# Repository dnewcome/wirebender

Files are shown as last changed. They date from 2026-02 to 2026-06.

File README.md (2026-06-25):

# CNC Wire Bender

A CNC wire bending machine capable of bending 14 or 16 gauge steel wire into arbitrary 3D shapes using G-code.

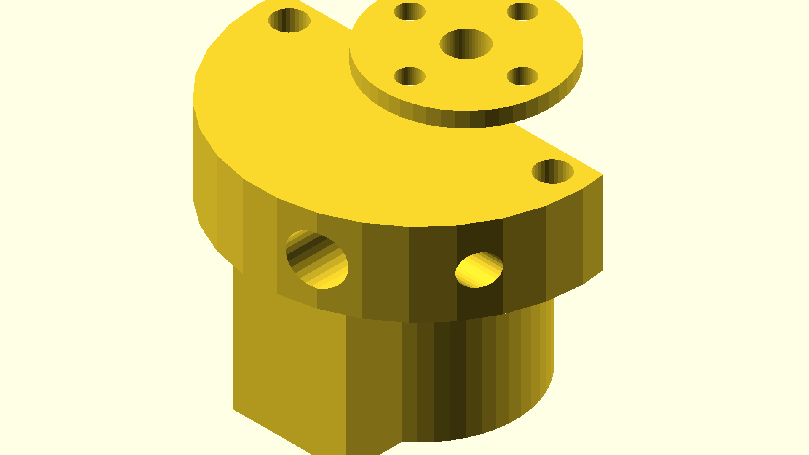
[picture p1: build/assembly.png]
Assembly


## Overview

Wire is fed from a spool using a 3D printer extruder, through a rotating feed tube. The feed tube rotation sets the bend plane (direction), and a bending head fixed to the end of the tube performs the actual bend. Motion is controlled by a GRBL 1.1 board.

## Machine Architecture

### Motion Controller
- **Controller:** GRBL 1.1
- **Input:** Standard G-code

### Wire Feed
- **Component:** Off-the-shelf 3D printer extruder
- **Wire gauge:** 14 or 16 AWG steel wire fed from a roll
- **Feed path:** Extruder → feed tube → bending head

### Feed Tube (Rotation Axis)
- Rotates around the wire axis to set the bend direction
- Driven by a geared stepper motor via toothed belt
- Supported by bearings housed in a U-shaped sheet aluminum bracket
- The U-bracket is extended to also mount the tube rotation motor

### Bending Head
- A cantilevered head clamps the end of the passive feed tube and **rotates about
  the wire axis** (Axis 2), carrying the bend mechanism around with it.
- **Bend drive (Axis 3):** a 20:1 micro-cycloidal drive + pancake
  NEMA17. A pin on the cycloidal output sweeps the wire around a fixed mandrel —
  single-pin bending; bend radius is set by the mandrel.
- **Rotation drive (Axis 2):** a pancake NEMA17 + a 12T pinion meshing a fixed 40T
  gear on the base; the rotation motor hangs at the mesh radius and doubles as a
  counterweight.
- **Tube clamp:** the head grips the feed tube on a short boss with an M3 set screw.

## Building the parts

The machine is modeled in **build123d** (`cad/*.py`), assembled into a **MuJoCo**
sim (`sim/`), and the CAD↔sim machine parameters live in one place
(`sim/machine.py`). Everything is driven by the `Makefile`:

```bash
python3 -m venv py
./py/bin/pip install build123d gggears mujoco trimesh numpy pillow networkx manifold3d

make parts        # base plate / uprights / fixed gear / spacer (printable STLs)
make head         # printable head pieces (rot + bend) + pinion + reference meshes
make cyclo-drive  # the cycloid drive: ring + disc + shaft + base + end-cap (+ fit-check)
make model        # assemble the MuJoCo model (sim/wirebender.xml) from the STLs
make view         # open the interactive sim (head auto-sweeps its limits)
make assembly     # full machine as one build123d STEP (build/assembly.step)
make              # list all targets
```

The **bend drive is fully parametric** — no external CAD file is read at build time. The
**canonical machine targets 14 ga steel on the current motor** (the 20:1 / Ø42 drive), and
the same generator scales to heavier stock by one knob:

```bash
make drive                              # what wire can this machine bend + the driver current it needs
make cyclo-drive PINS=30 MOTOR=nema23   # a complete SCALED drive (Ø60 / 30:1, NEMA23) for 1/4" stock
```

See **`docs/DRIVE_SIZING.md`** for motor/driver sizing, the scaling family, the clearance
planner, and homing. Generated artifacts land in `build/` and `sim/meshes/` (both gitignored
— reproduce from source); `STRUCTURE.md` is the repo layout, `PLAN.md` the roadmap, and
`sim/README.md` the simulation + G-code toolchain.

The cycloid internals were **validated once against a purchased reference part** (not
redistributed), then rebuilt fully parametrically — no external CAD file is needed to build
any part.

## Checklist

*The CAD, the MuJoCo simulation, and the slicer/planner/drive-sizing toolchain are well
advanced. The remaining open items are mostly physical fabrication, wiring, and on-machine
calibration.*

### Mechanical Design
- [x] Parametric bending head — rotation + bend mounts and tube clamp (`cad/rothead.py`)
- [x] Fully parametric cycloid drive — ring, disc, eccentric shaft, base, end cap; scales by
  ratio/motor (`make cyclo-drive PINS=.. MOTOR=..`)
- [x] Bend pin / mandrel geometry defined + clearance-checked in sim (`cad/bend_disc.py`, `make check-pin`)
- [x] Feeder motor mount + bracket (`cad/feeder_motor_mount.py`, `cad/feeder_bracket.py`)
- [x] Feed tube → 608-bearing sleeve adapter + bearing selection (`cad/sleeve.py`)
- [x] Rotation drive sized — 12T pinion on a fixed 40T base gear (replaces the earlier belt/pulley idea)
- [x] Homing-switch brackets, Axes 2 & 3 (`cad/home_switch.py` + `cad/arbor_mount.py` home tab)
- [ ] U-shaped sheet-aluminum feed-tube bearing bracket (fabricate)
- [ ] Wire guide / straightener between spool and feeder

### Electronics & Control
- [x] Axis assignments confirmed — Axis 1 wire feed, Axis 2 head rotation, Axis 3 bend
- [x] Stepper-driver sizing + phase-current requirements modeled per machine (`make drive`, `docs/DRIVE_SIZING.md`)
- [x] Axis limits + homing strategy defined (conventions in `sim/machine.py`, cycle in `sim/home.py`)
- [ ] Wire up GRBL 1.1 board and stepper drivers
- [ ] Set driver current to rated + tune microstepping (bench)
- [ ] Calibrate steps/mm for each axis (bench)

### Software / G-code
- [x] G-code workflow decided — model → slicer → clearance-aware planner → verified program
- [x] Path generator / post-processor (`sim/slicer.py`, `sim/plan.py`)
- [x] Clearance planner + whole-path collision verify (`sim/clearance.py`, `sim/plan.py`)
- [x] Feed / rotate / bend sequences validated in sim (`make anim`, `make run`)
- [x] Homing + initialization routine designed and simulated (`make home`)

### Fabrication (physical)
- [ ] Print the head pieces (`make head`) and fit on the cycloid / rotation motors
- [ ] Bend + drill the U-bracket sheet-aluminum pieces
- [ ] Assemble feed tube with bearings into the bracket
- [ ] Full mechanical assembly + fit check

### Validation (bench)
- [ ] Dry-run all axes, no wire — travel + direction (verified in sim; confirm on hardware)
- [ ] First wire feed test with soft wire (e.g. aluminum) before steel
- [ ] Calibrate bend angle vs. motor steps + `BEND_PROCESS_FACTOR`
- [ ] Measure + compensate springback in 14/16 ga steel
- [ ] Produce a simple test shape (square, circle)

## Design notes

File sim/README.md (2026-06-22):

# MuJoCo simulation + G-code toolchain

A rigid-body MuJoCo model of the wire bender, assembled directly from the
**printable** build123d STLs, plus the forward model / slicer / rule-checker that
turn shapes into G-code and back. All machine parameters come from one source of
truth, `machine.py` (kept in sync with the CAD by `consistency.py`).

## The model (`make_mjcf.py` → `wirebender.xml`)

Assembled from the actual part STLs — what you see is what you print:

| Mesh | Source | Role |
|---|---|---|
| `base` | `build/base.stl` | printable: deck + uprights + fixed gear + spacer |
| `head` | `build/rothead.stl` | printable: head bracket (rot + bend pieces) |
| `pinion` | `build/pinion.stl` | printable: rotation pinion (animated, meshes the fixed gear) |
| `arbor_mount`| `build/arbor_mount.stl` | printable: rotating cyclo housing + posts (bend output) |
| `end_cap` | `build/end_cap.stl` | printable: turned-down cyclo end cap (fixed, caps the arbor) |
| `bend_plate` | `build/bend_plate.stl`| printable: cyclo base + side boss (fixed; bend motor on its back) |
| `head_refs`  | `build/head_refs.stl` | **reference** (purchased): NEMA motors + cycloid drive |
| `feeder` | `build/feeder_body.stl` | reference primitive (1KGSSJ-B feeder) |

Joints (collisions are off — kinematic visualization, driven by actuators):

| Joint | Type  | Axis | Function |
|---|---|---|---|
| `tube_rot` | hinge | wire axis (X) | Axis 2 — bend **direction** (head roll) |
| `bend` | hinge | cycloid axis (Z) | Axis 3 — bend **degree** (270° travel) |
| `pinion_spin` | hinge | pinion axis | display only — rolls on the fixed gear, `= tube_rot × machine.PINION_RATIO` |

Wire **feed** (Axis 1) is kinematic — the formed wire grows out of the head in
`animate_bend.py`, not a sliding joint. A `pin` site + `pin_pos` sensor track the
bend-pin tip.

```bash
cd sim && MUJOCO_GL=osmesa ../py/bin/python make_mjcf.py   # or: make model
DISPLAY=:0 ../py/bin/python view.py                        # or: make view
```

`view.py` auto-sweeps each axis through its limit (head roll + 270° bend),
interference-free; `view.py --manual` gives draggable sliders.

## Predicting the wire shape (`bend_model.py`)

A deterministic forward model: feed it a bending **program** (`feed` / `rotate` /
`bend` ops) and it walks a moving frame along the wire to compute the resulting
**3D shape**, with a springback factor. Bends are arcs of radius
`machine.BEND_RADIUS` (mandrel radius + wire radius ≈ 2.8 mm at 14 ga; pass
`bend_radius=0` for sharp corners), so predicted lengths include the wire consumed
in each arc.

```bash
../py/bin/python bend_model.py                         # simulate the examples
MUJOCO_GL=osmesa ../py/bin/python bend_model.py --png   # render to preview/shapes.png
```

Example programs live in `EXAMPLES` (square, staple, chair, coil).

## Animating a program on the machine (`animate_bend.py`)

Runs a program **on the machine**: the head rolls (Axis 2), the bend die sweeps
(Axis 3), the pinion meshes the fixed gear, and the formed wire grows out of the
head. Before running it **enforces the machine limits** (`interference.py`): on an
error-severity violation it animates up to the faulting bend, then **halts with a
magenta fault marker** and a non-zero exit (`--force` overrides).

```bash
MUJOCO_GL=osmesa ../py/bin/python animate_bend.py staple    # -> preview/bending_staple.gif
../py/bin/python animate_bend.py chair --view               # live playback (needs a display)
../py/bin/python animate_bend.py part.gcode                 # run a sliced program
```

## Slicer: model → G-code (`slicer.py`)

The inverse of `bend_model.py`, a pluggable framework: an **extraction method**
turns a source into one or more wire paths, then a shared backend recovers the
`feed`/`rotate`/`bend` program and emits G-code for the three GRBL axes (X = feed
mm, Y = tube rotation deg, Z = bend deg).

```bash
../py/bin/python slicer.py --list-methods
../py/bin/python slicer.py chair --check                 # built-in example + rule check
../py/bin/python slicer.py drawing.svg --tol 0.5 -o part.gcode
../py/bin/python slicer.py wire.stl --method centerline  # tube mesh -> spine
```

**Extraction methods** (`--method`, else auto-detected by extension):

| method | source | notes |
|---|---|---|
| `points` | `.json` / `.csv` | list of `[x,y(,z)]` |
| `svg` | `.svg` | first `<path>` (M/L/H/V/C/Q/Z), 2D |
| `example` | a name | a built-in `bend_model` example |
| `centerline` | mesh | tube mesh → extracted spine *(experimental)* |
| `cross_section` | mesh | slice a solid into contour loops (`--axis`, `--spacing`) |
| `edge_follow` | mesh | feature edges → wire (`--feature-angle`, `--single`) |

Feeds are shortened by `r·tan(α/2)` (setback) at each bend and bends
over-commanded by `1/(1-springback)`; **fit error** (max deviation from the input)
is reported. `--check` runs the rule-checker on each sliced path.

## Manufacturability rules (`interference.py`)

A **flag-only** checker for the single-pin bend cell. It walks a program (same
kinematics as `bend_model`) and reports per-bend violations of the machine limits:

- `travel` — bend command > `DIE_TRAVEL_DEG` (270° die range)
- `min_straight` — inter-bend straight too short for the setback + pin grab (this
  is where the fixed mandrel radius bites)
- `pin_part` — the pin sweep would strike the already-formed part
- `pin_tube` — wrap past `MAX_WRAP_DEG` swings the pin toward the feed tube
- `part_head` — the formed part swings back into the head body

```bash
../py/bin/python interference.py chair        # check an example (or a .gcode file)
../py/bin/python interference.py --caps        # print the machine limits
```

It's wired into `slicer.py --check` and enforced in `animate_bend.py`. The
clearance constants are calibratable placeholders (see `PLAN.md`).

## Drive sizing (`drive_model.py`, `make drive`)

"What stock can this machine bend, and what driver does it need?" Two limits — **torque**
(d³·σy·ratio·motor) and **printed-disc capacity** — plus the **phase current → driver class**
(stepper torque is current-set). Diagnoses stalls and sizes the cycloid body Ø for a target
wire. `make drive` · `make drive CURRENT=1.5` · `--rated-torque/--rated-current` to spec a
motor. Full sizing/scaling guide: **`../docs/DRIVE_SIZING.md`**.

## Clearance-aware planner (`clearance.py` + `plan.py`)

Collision-safe move generation for G-code:

- **`clearance.py`** — ground-truth bend-cell clearance: exact body poses from the MuJoCo
  model, distances against the **real non-convex STL meshes** (scipy KD-trees). The formed
  wire is fixed and the head orbits it; the fixed die exit is excluded so only *avoidable*
  swing/rotation hits are flagged.
- **`plan.py`** (`../py/bin/python plan.py <example>`) — per bend, chooses the head-rotation
  direction (short vs **long-way backtrack**) + a **feed-to-clear**; `plan.verify()` replays
  the whole interpolated motion and hard-fails any frame below margin.
- **Visualize:** `make anim-view NAME=chair ARGS=--plan` (or `make anim … ARGS=--plan`) —
  planned moves, wire coloured by live clearance (green/amber/red).

## Other tools

- **`machine.py`** — single source of truth for the machine parameters (axis heights, tube,
  mandrel/pin/die, wire, gear ratio + cycloid drive + motor/driver, `BEND_RADIUS`, limits).
- **`consistency.py`** (`make check-consistency`) — asserts `machine.py` matches
  the CAD constants so they can't drift.
- **`check_pin.py`** (`make check-pin`) — sweeps the axes and reports the bend
  die's mesh-level clearance to the feed tube (`mj_geomDistance`).
- **`render.py`** — headless montage / still renders.

## Setup

```bash
python3 -m venv py
./py/bin/pip install mujoco trimesh numpy pillow networkx
```

## Notes

- Geometry is mm in CAD; the model scales to metres (`scale="0.001"` on meshes).
- `make_mjcf.py` reads the STLs in `build/` — run `make parts head` first if
  they're missing.
- Collisions are off in the sim (kinematic viz); `interference.py` checks
  manufacturability offline and `check_pin.py` checks mesh clearance.

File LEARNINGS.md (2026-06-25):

# Learnings

Notes on what's worked well while building this machine, so we don't relearn it.

## Read the STEP, then re-create vendor geometry parametrically in build123d

When working with a purchased part supplied as a STEP file (e.g. a
`20-1 Micro Cycloidal.step` assembly), it pays to **inspect the B-rep directly** and then
**re-create the geometry as a parametric build123d model** rather than carrying the vendor
mesh around.

**Inspecting the STEP is genuinely useful.** build123d can import the assembly, list its
named children (`Housing_v1`, `End_Cap`, `Base_-_Nema_17`, …), and enumerate each solid's
edges and faces with their *semantic types* — `CYLINDER`, `CONE`, `PLANE`, `CIRCLE`,
`BSPLINE` — plus exact radii, centers, and z-planes. That turns "stare at an STL" into
"query the actual design intent." Two payoffs we hit directly:

- **It exposes what a shape really is.** The cyclo Housing's internal "gear" *looked*
  epicycloidal in a render, but the faces were 20 `CYLINDER`s (Ø3 pins on an 18.39 pitch
  radius, 18° apart) + `CONE` chamfers, with **zero B-spline faces** — the 80 B-spline
  *edges* were just the intersection curves where round pins meet the bore. Measuring the
  faces settled "cylindrical-with-chamfers vs. epicycloidal" in seconds; eyeballing the mesh
  could not.
- **It gives exact dimensions to rebuild from.** The `End_Cap` was reconstructed as a clean
  revolve + 6 counterbored holes using radii/z-planes read straight off its circular edges.

**Re-creating it in build123d recovers semantic information the mesh has thrown away.**
An STL is just triangles — no notion of "this is a Ø40 flange," "these are 6 M3 counterbores
on a r10.125 circle," "this is the turn-down amount." Once the part is a parametric script,
those concepts are *named variables and operations*, so later edits are trivial and
intention-revealing: turning the End_Cap OD down 2mm is `R_FLANGE = (42 - OD_TURNDOWN)/2`;
the bolt pattern is a loop. Modifying a mesh to achieve the same thing is fragile guesswork.

**Reading the code beats re-probing the geometry over and over.** A parametric `.py` is the
single, legible source of truth for a part. You read the dimensions and features once, in
context, instead of repeatedly loading the STL, slicing sections, and ray-probing to
re-discover what something is. It also makes the part vendor-independent and instant to
rebuild.

Caveats:
- The vendor tessellation can be unreliable — the `End_Cap` STEP had 8 degenerate
  ("null triangulation") faces that OpenCASCADE couldn't mesh at any tolerance, so 4 of its
  6 holes dropped into detached, non-watertight shells and a slicer only printed 2 holes.
  A parametric rebuild sidesteps broken vendor tessellation entirely.
  - **The tell: screw holes vanish in the file conversion.** Converting the vendor part to a
    meshed B-rep kept losing the End_Cap's bolt holes (only 2 of 6 survived). That symptom —
    holes silently dropping on export — is the canonical reason this project re-creates vendor
    geometry parametrically rather than shipping the imported mesh.
- **Standing goal: no vendor geometry in the build path.** Read the STEP (B-rep, exact) to
  *measure* dimensions, but ship a parametric rebuild so the build depends on no purchased
  STEP/STL (which are paid/not-redistributable anyway). The STEP is the source of truth for
  numbers; it is not a build dependency. Done: `housing.py`, `end_cap.py`, and `cyclo_base.py`
  (the parametric `Base_-_Nema_17` rebuild — `bend_plate.py`/`bend_plate_90.py`/`rothead.py`
  now build off it with OCC booleans, so the vendor base STL is no longer read by the build;
  the orphaned `gen_vendor.py` STEP-reader was removed). Prefer the STEP B-rep over the STL
  when measuring — the mesh is a lossy tessellation; the B-rep gives exact radii/centres (and
  is where the holes are intact).
- When the vendor solid *does* tessellate cleanly (the `Housing_v1` mesh is watertight) and
  its surface is intricate, a faithful STEP extraction is fine to keep — but even then,
  reading the B-rep tells you the geometry is simple enough (20 plain pins) that a parametric
  version would be just as exact if you later need to modify it.

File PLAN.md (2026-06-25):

# Wire Bender — Plan & Roadmap

Forward-looking plan for the CNC wire bender, focused on the design + simulation
work. (The build/fabrication checklist lives in `README.md`.) Items are roughly
ordered; check them off as they land.

## Status snapshot (2026-06-10)

- **Sim:** full machine roughed in (`sim/`), all three axes (`feed` / `tube_rot`
  / `bend`) drivable. Bending head uses real CAD meshes; feeder, NEMA17, feed
  tube, pulley, U-bracket, rotation motor, and wire are rough primitives.
- **Forward model:** `sim/bend_model.py` predicts the 3D part from a program.
- **Animation:** `sim/animate_bend.py` runs a program on the machine (wire forms
  out of the head); verified to match the forward model exactly.
- **Interference:** `sim/interference.py` checks self / table / body collisions
  (exact) and head clearance (approximate — see below).

## Head — simpler 2-part redesign (2026-06-14)

The cantilevered rotating head is being **simplified**. The current `cad/rothead.py`
grew into a multi-feature bracket (pinch-clamp hub + rotation arm + bend spine,
then a bolted 2-piece split). We're collapsing it to a cleaner set of parts.
Dan is sketching the geometry by hand; this section is the design intent to build to.

**Target: 2 parts.**

1. **Main part** — one printed bracket that carries everything, with three features:
   - **Slotted NEMA17 mount** (rotation motor) on one side. Radial slots so the
     motor/pinion slides to set the pinion ↔ fixed-gear mesh (backlash). Carries
     over from today's `rot_mount()` (slots already done, ±`ROT_SLOT`).
   - **Slotted bending-head boss** on the *other* side. A boss/socket that the
     cycloid-base part (below) mates into, with slots so the bend head's height
     above the wire is adjustable (±`BEND_SLOT`). Replaces today's two slotted
     tabs + yoke with a single boss.
   - **Central circular boss with a set screw** — mounts the head onto the feed
     tube. Replaces the pinch-slit clamp hub: a plain round bore (tube Ø) + a
     radial set screw (heat-set insert + grub, like the pinion) clamps the tube.

2. **Cycloid-base part** — a **boss built onto the cycloid plate**, roughly as
   already prototyped (`cyclo_base()` import, oriented bearing-boss-down toward
   the wire; the version with 2 heat-set threaded inserts). This boss slides into
   the main part's bending-head boss and bolts through the height slots into the
   inserts.

**Carry over from the current code:** `_slot()` helper, the slotted `rot_mount()`,
the `cyclo_base()` STL import (boss-down), the slot-travel constants.
**Drop:** the pinch-clamp `hub()`, the rotation `bend_spine`/yoke/tabs, and the
bolted 2-piece `rot_piece`/`bend_piece` split (`build/rothead_rot.stl`,
`rothead_bend.stl`). The main part becomes a single body; the cycloid-base boss
is the only other printed piece.

**Open (Dan to pin down in the sketch):** the bending-head boss/socket profile
(how the cycloid boss registers + slides), set-screw boss diameter/wall, and the
exact insert spacing on the cycloid boss (today's slots assume `CYC_INS_Y=±14`,
`CYC_INS_Z=12.5` on the base +X face — re-match once the sketch lands).

## Mechanical stiffening / robustness (2026-06-18)

The feeder grip and bend-head torque are now strong enough that the surrounding
brackets are the weak links. Stiffening pass:

- [x] **Front upright foot + gussets** (`cad/base.py`). The thin 8mm blade is now a
  braced L-bracket: a 6mm rearward foot (x≈12→36 — can't extend forward, the deck
  edge is at x=10 and the fixed gear hangs in front), two triangular gussets
  (`GUSSET_*`) over the bolt lines rising 22mm up the blade back, and two extra
  deck bolts at the foot rear (`FRONT_FOOT_BOLT_X`) that widen the X bolt base.
  `base_plate()` carries the matching counterbored mounts. One watertight body.
- [x] **Arbor plate** (`cad/bend_disc.py`). Was Ø60 × 2mm. Now **3mm** thick (more
  material around the countersinks for the bend reaction), still bolted to the arbor
  posts with 4× **M3 countersunk** screws into the existing M3 inserts (arbor_mount
  unchanged). (Still optional: a short boss around the mandrel/bend-pin holes if the
  pins work loose.)
- [ ] **Bend-disc tooling variants** (`cad/bend_disc.py`, design notes in the file). The
  disc separates two pins with different jobs, and we'll ship a family of plates:
  - **Outer bend pin** (`PIN_OFFSET`) sets the minimum bend **length** — sweep its radius
    across versions: smaller wire runs it closer in, heavier wire further out. Planned:
    swap the fixed pin for a larger **roller** (shoulder screw / small bearing) so the wire
    rolls rather than drags as it wraps (less marring, lower friction, more force headroom).
  - **Centre mandrel** (`MANDREL_D`) sets the minimum bend **radius** (r ≈ MANDREL_D/2 +
    wire/2) and is **floored by wire size** — it must be stout enough not to deflect under
    the bending force, so it's the strength-constrained pin; size it per wire/bend-radius.
- [ ] **rothead bending neck** (`cad/rothead.py`, `flat_head()`). The bending plate
  is lifted 12mm (`FH_BEND_LIFT`) on a 5mm-thick, 13mm-wide neck (`bneck`) — a
  slender cantilever. Widen the neck in Y and thicken the central spine/web tying
  it to the boss (in-plane stiffening, keeps the flat-print orientation).
- [ ] **Bender right-angle mount** (`cad/bend_plate_90.py`). The riser is a 6mm tab
  (`RISER_T`) cantilevering 22mm (`RISER_H`) up off the flange. Add a pair of
  triangular side gussets from the flange arm up the riser back (trimesh prisms),
  and/or bump `RISER_T`.

## Bend drive (cycloid) + machine sizing

**Canonical machine: 14 ga steel on the current motor (the 20:1 / Ø42 drive).** 14 ga needs
~0.5 N·m so margin is large; get this fully working first. Everything below is the documented
**scaling path** for heavier stock — full details + numbers in **`docs/DRIVE_SIZING.md`**.

- [x] **Fully-parametric cycloid drive** (`cad/cycloid.py` + `housing.py` + `cyclo_base.py` +
  `end_cap.py`). Disc + eccentric shaft validated vs the vendor STEP/BOM (lobe profile RMS
  0.04 mm, E=0.625; press-fit D-bore shaft; support journals Ø7). The whole drive reads no
  vendor file. **Scales by one knob:** `make cyclo-drive PINS=30 MOTOR=nema23` keeps the lobe
  size + eccentric core (shaft/bearings reused), grows the ring/disc, and switches the NEMA
  mount. `make check-cyclo PINS=…` confirms the disc meshes. Default (20 pins / nema17) is
  byte-identical to the validated drive.
- [x] **Design explorer + driver sizing** (`sim/drive_model.py`, `make drive`). Two limits —
  torque (d³·σy·ratio·motor) and printed-disc capacity — plus **phase-current → driver class**
  (stepper torque is current-set). Diagnoses stalls (current-deficiency vs motor-insufficiency)
  and sizes the body Ø for a target wire (1/4″ mild ≈ Ø62 / 30:1 at 1.5× on the NEMA23).
  Reproduces the bench stalls. Machine-bound, not disc-bound, in every case.
- [x] **Clearance-aware motion planner** (`sim/clearance.py` + `sim/plan.py`). Mesh
  ground-truth clearance; per-bend rotation backtrack + feed-to-clear; `plan.verify()`
  whole-path safety gate; `--plan` clearance-coloured animation. (See the Interference section.)
- [ ] **Calibrate the model against real bends.** `BEND_PROCESS_FACTOR` (1.6), `MATERIALS`
  allowables, `PEAK_CARRIER_SHARE`, and wire σy by temper — fit to measured stall torque /
  disc wear once the canonical machine runs.
- [ ] **Stout mandrel / roller-pin `bend_disc`** sized for the 27–55 N·m reaction of heavy
  stock (steel pins) — the strength-constrained part once the drive can deliver the torque.
- [ ] **Homing switches** — Axis 2 (bend plane) + Axis 3 (bend die, the critical one);
  flag-on-output + fixed switch, optical/hall preferred; `machine.py` offsets + GRBL cycle.
- [ ] **Optional disc bearing land** (Ø11 × 0.75 vendor feature) once the press fit is dialed.
- [ ] **Tube bending (future).** `drive_model.py` takes `kind="tube"`, but torque is
  necessary-not-sufficient: needs a mandrel/wiper wrinkle + ovalization model.
- [ ] **Reusable kinematic kernel** for 3rd-party tools — `machine.json` profile + JSON CLI
  (see `docs/DRIVE_SIZING.md`).

## Wire / bend modeling

- [x] **Bend radius (filleted corners).** Bends now lay an arc of radius
  `bend_model.BEND_RADIUS` (default 4 mm — the wire wrapping the mandrel) instead
  of a sharp corner, in both the forward model and the machine-frame animation
  (verified congruent). `bend_radius=0` recovers sharp corners. *Still to do:*
  calibrate the radius to the real mandrel/shoe geometry.
- [x] **Wire consumed in the bend arc.** Total wire length now includes the arc
  length at each bend (Σ feed + Σ r·α), so `total_length` reflects real usage.
- [ ] **Springback calibration.** `springback` is a placeholder (0). Bend test
  coupons of 14/16 ga, measure commanded vs realized angle, and fit a model
  (likely angle- and material-dependent). Feed that back into `bend_model.py`.
- [ ] **Plastic wire physics (optional, later).** Route B: a segmented wire in
  MuJoCo whose hinges yield and hold past the shoe, so the wire looks real in the
  3D view and responds to contact. Route C: full flex/contact. Only if the
  deterministic model isn't enough.

## Interference / collision

- [x] **Manufacturability rule-checker** (`sim/interference.py`, rebuilt 2026-06-15).
  Flag-only checker that walks a program (same kinematics as `bend_model`) and
  reports per-bend violations of the single-pin bend-cell limits:
  `travel` (bend cmd > `DIE_TRAVEL_DEG`=270° die range, exact), `radius` + `min_straight`
  (inter-bend straight < pin grab / setback, exact — fixed mandrel radius
  `BEND_RADIUS = mandrel_r + wire_r`), `pin_part` (pin sweep strikes the formed
  part, approx), `pin_tube` (wrap > `MAX_WRAP_DEG` swings the pin toward the feed
  tube, calibratable), `part_head` (formed part swings back into the head, approx).
  Wired into `slicer.py --check`; CLI `interference.py <example|part.gcode>` /
  `--caps`; `make rules`. Verified: square/staple/chair pass, tight `coil` flags
  pin_part + min_straight, 300° flags travel.
- [ ] **Calibrate the clearance constants** against the real head once the head
  redesign lands: `MAX_WRAP_DEG` (180° placeholder — the angle past which the pin
  returns toward the tube), `MIN_GRAB`, `PIN_SWEEP_R`, the `HEAD_BACK_REACH`/
  `HEAD_RADIUS` keep-out. The mesh-level pin↔tube clearance is measured by
  `check_pin.py` — now **+4mm clear** across the full axis range after orienting
  the bend die body-up (`make_mjcf`); flipped body-down it buried the pin in the
  tube. NOTE: clearing requires the die body to point away from the wire, which
  only fully works once the head redesign ends the feed tube before the bend
  point (today's tube still runs through it). The real die orientation must come
  from the head CAD; the sim quat just reflects the intended (clear) build.
- [ ] **Upgrade `part_head` to the real head mesh.** Today it's a parametric
  keep-out box behind the bend point; place the formed part in the machine frame
  and run a signed-distance check against the actual head STL (like `check_pin`).
- [x] **Single source of truth + sim enforcement** (2026-06-15). `sim/machine.py`
  holds all machine params (axis heights, tube, mandrel/pin/die, wire, derived
  `BEND_RADIUS`, the calibratable limits); `bend_model`, `interference`,
  `check_pin`, `make_mjcf`, `animate_bend` all read from it, so the CAD, sim,
  forward model, slicer, and rules describe one machine. `sim/consistency.py`
  (`make check-consistency`) asserts machine.py matches the CAD constants.
  `animate_bend` now runs the rule-checker first and, on an error-severity
  violation, animates up to the faulting bend then HALTS with a magenta fault
  marker + nonzero exit (`--force` overrides). Fixed drift this exposed:
  `BEND_RADIUS` 4→2.8 (mandrel-derived) and the animator's stale `ZAXIS_MM` 21→41.
- [ ] **Reachability / envelope check.** Beyond collisions: does a program stay
  within axis travel limits (feed length, tube-rotation range)?
- [ ] **Wire-vs-already-formed-part as the part grows** is handled; revisit once
  bends have radius (sharp corners slightly over/understate clearance).

## G-code workflow

- [x] **Slicer (CAD path → G-code).** `sim/slicer.py` is the inverse of the
  forward model: a wire path (points / SVG / example) → `feed`/`rotate`/`bend`
  program → G-code, with setback + springback compensation and fit-error
  reporting. Inverse kinematics verified exact (0 mm sharp round-trip). Imports:
  `.json`/`.csv` points, `.svg` paths.
- [ ] **More path imports:** DXF (2D), STEP / 3D CAD edges/wires. Today curves
  are polygonised into discrete bends.

### Slicing methods (model → wire path(s)) — pluggable framework

Refactor the slicer so a 3D model can be turned into wire path(s) by one of
several interchangeable **extraction methods**, all feeding the shared backend
(simplify → `feed/rotate/bend` → fit error → interference → G-code). Each method
returns one or more paths; the backend already verifies any path.

- [x] **Framework refactor.** `slicer.py` has a method registry (`METHODS`),
  `--method`/auto-detect, and multi-piece G-code (cut/reload `M0` between pieces).
  Registered: `points`, `svg`, `example`, `centerline`.
- [x] **Centerline** (tube/curve → 1D spine). Cross-section marching; round-trips
  well on chair (fit 0.32 mm) and the U-shaped staple (102.9 vs 102.6 mm).
  *Experimental* — tight/self-touching tubes may need a `--tol`/step tweak.
- [x] **Cross-section** (solid/surface → contours at intervals → wire loops, like
  an FDM slicer). `--method cross_section --axis --spacing`; each contour loop is a
  wire piece. Verified: sphere → ring cage (fit ~0.3 mm), box → rectangles.
- [x] **Edge-following / wireframe** (feature edges → wire), pepakura-flavored.
  `--method edge_follow --feature-angle`. Builds a graph of sharp edges and, by
  default, decomposes each component into the fewest open trails covering every
  edge once (separate wire pieces, no overlap). `--single` forces one strand via
  Eulerian augmentation (retraces edges → large fit error, flags impracticality).
  Verified: box → 4 pieces covering all 12 edges. *Future:* include boundary edges
  of open meshes; smarter odd-vertex pairing (shortest-distance) to minimize pieces.
- [ ] **Outline / silhouette** (project → outline) for 2D-ish parts.
- [ ] **Hybrids** (e.g. cross-section ribs + connecting spine).

**Cross-cutting constraint:** the bender makes a *single continuous strand*, so
multi-path output means either separate wire pieces (cut/weld) or one routed path
that doubles back. Methods must also respect manufacturability (reachability, min
straight between bends, bend-radius limit) — reuse `interference.py` per path.
- [ ] **Axis assignment + steps/mm** (mirror the README electronics checklist):
  Axis 1 feed (extruder), Axis 2 tube rotation, Axis 3 bend. Calibrate steps/mm
  per axis; map G-code units → physical motion in the parser.

## Hardware / CAD (replace rough primitives with real geometry)

- [x] **Stepper mount + drive gear** (done — superseded the old `stepper-adapter.scad`
  / `feeder-gear.scad`, both deleted). The NEMA17 mount is now integrated into
  `cad/feeder_bracket.py` (motor pocket / slotted web / boss pocket), and the drive
  pinion is `cad/feeder_gear_press.py` (11T m0.8, press-fit D-bore, 12mm engagement).
- [ ] **Replace primitives with CAD** in the manifest: feeder body, feed tube,
  U-bracket + bearings, tube-rotation motor + belt/pulley. Then `make_mjcf.py`
  picks them up as real meshes and the sim/interference geometry gets accurate.
- [ ] **Belt/pulley sizing** for the feed-tube rotation axis (README checklist).
- [ ] **Wire guide / straightener** between spool and feeder.

## Validation (once hardware exists)

- [ ] Dry-run all axes (no wire) — verify travel + direction vs sim.
- [ ] First feed test with soft wire, then 14/16 ga steel.
- [ ] Calibrate bend angle vs motor steps; measure springback; feed back to model.
- [ ] Produce a test shape (square / circle) and compare to the predicted part.

## Future direction — clamp-on "crawler" bender (north star, not canonical)

The only ground-fixed part of the machine is the **feeder**; the rotation axis, cycloid, and
mandrel/pin all already ride the head. So invert the feed axis — instead of *pushing wire
through a fixed head*, **crawl the self-contained head along fixed stock** (clamp onto a
tube/rod and traverse it, bending in place). A portable / in-situ former: no spool, no bench.

- **The software is already relative.** `bend_model` treats "feed N mm" as the relative
  advance between wire and head, so the forward model, slicer, clearance planner, and homing
  carry over unchanged — feed just remaps from extruder-steps to **crawl distance** along the
  tube. The existing toolchain already describes a crawler.
- **Three mechanical changes:** (1) a **crawl drive** that grips + translates precisely along
  the tube (friction wheels / pinion-on-clamped-rack / leadscrew) — slip = lost feed, so it
  wants a **closed-loop encoder** (dovetails with the closed-loop-stepper idea for the stall
  problem); (2) an **openable / split rotary bearing** so Axis 2 can encircle a clamped tube
  (today it rotates about the wire with the wire passing through); (3) **anchoring** so the
  bend reaction (≈27 N·m at 1/4″) reacts through the grip without the crawler spinning/sliding.
- **Hard limit — tube bending in place.** A free wire forms only at its trailing end, so
  crawling **wire/rod** (or large-radius, thick-wall tube) progressively **from a free end** is
  the same problem already solved (the formed part trails the crawler like it trails the fixed
  head today). But tight-radius thin-wall tube needs an internal draw-mandrel/wiper, which
  **can't be threaded into a continuous tube mid-span while crawling** — so the crawler is
  naturally a wire/rod or conduit-style large-radius machine, not a tight thin-wall tube bender.
- Orthogonal to the canonical 14 ga machine — pursue only after that's working.

## Future direction — threadless-ball-screw ("chuck") feeder (not canonical)

Alternative to the geared pinch feeder (1KGSSJ-B repurpose): a **threadless ball screw** /
Uhing rolling-ring drive — 3 bearings skewed at angle α, closed like a self-centering chuck
against the round stock; **spin the chuck** and the skewed rolling drives the stock axially.
The wire is the "screw", the chuck is the "nut"; the formed bends downstream hold the wire
from rotating, so it only translates.

- **Kinematics:** `feed_per_rev = π · D_stock · tan(α)` (e.g. 1/4″ rod at 8° ≈ 2.8 mm/rev,
  0.150″ wire at 8° ≈ 1.7 mm/rev). Note the **lead is stock-diameter dependent**, so feed
  becomes a *calibrated per-stock* constant, not a fixed mm/step. Feed is now a **rotary axis**
  (likely belted up from the chuck).
- **Why it's attractive:** 3-point symmetric grip → **zero net side load** (wire stays
  straight, unlike a 2-wheel pinch); **adjustable clamp = adjustable thrust** for heavier stock;
  clean **bidirectional + unlimited travel** (serves the planner's feed-forward/back backtrack).
- **Needs independent feed sensing.** It's a *friction* drive — under thrust it can slip and
  silently lose feed length, and feed length sets bend spacing. Close the loop on *actual* wire
  travel, not commanded chuck revs; that also absorbs the diameter-dependent lead and any α
  drift. (Same closed-loop theme as the stall fix and the crawler crawl-drive.)
  - **Preferred: non-contact laser optical sensor.** A laser-mouse motion sensor (VCSEL
    speckle, e.g. ADNS-9800 class — *not* an LED imager; bright/shiny stock is the case laser
    mice exist for) reads the wire's surface motion directly, so there's nothing of its own to
    slip and no marring. Resolution is a non-issue (~25 µm/count at 1000 CPI vs ~0.1 mm needed).
    Constraints: hold the wire in a **V-groove/bushing under the lens** at the ~2.4 mm focal
    standoff (a round surface only shows a thin in-focus strip — easier on 1/4″ rod than thin
    wire); align the sensor's X with the feed axis; **calibrate counts/mm per material+finish**;
    and **fault on the surface-quality (SQUAL) register dropping** — a tracking dropout reads as
    zero feed = the exact silent under-count we're guarding against (felt wiper ahead of it for
    oil/scale). Speed/accel limits (~6 m/s) are far above feed.
  - *Fallback / cross-check:* a decoupled measuring wheel + rotary encoder riding the wire
    (robust on any finish, but can itself slip and marks the stock). Optical primary + wheel
    sanity-check is the belt-and-suspenders option.
- **Enables the crawler.** This *is* a candidate crawl-drive (see above): fix the tube, let the
  spinning chuck react against it, and the whole head walks the stock — collapsing the last
  ground-fixed part (the feeder) onto the head.

## Notes / decisions

- MIG feeder (1KGSSJ-B) chosen for the wire feed; brushed motor + gear reduction
  already feeds 14 ga fine, so a NEMA17 through the same gearbox is plenty.
- Keep the existing gear reduction (torque + resolution); don't direct-drive.
- Sim is kinematic (collisions off) by design; `interference.py` does collision
  checks offline against the formed-wire geometry instead.
- **Manufacturability: the sim assembles the PRINTABLE part STLs** (base, rothead
  rot+bend, pinion, bend die) — what you see is what you print. Purchased parts
  (NEMA motors, cycloid drive) are shown as a clearly-separated REFERENCE mesh
  (`build/head_refs.stl`, from `cad/head_refs.py`, placements imported from
  `rothead.ghosts()`), never fused into a printable STL. CAD print scripts stay
  clean (one printable part each). The rotation pinion is its own animated body
  meshing the fixed gear (spin = head roll × `machine.PINION_RATIO`); motor
  bodies are shown but their internals aren't animated (torque/efficiency is a
  later numerical study, not the visualization).

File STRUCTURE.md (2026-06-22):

# Repo layout

## Source — edit these

| Path | What |
|---|---|
| `cad/gears.py` | involute spur-gear generator (build123d) |
| `cad/base.py` | **the base** — fixed gear + 2 bearings + feeder mount |
| `cad/rothead.py` | **the rotating head** (work in progress) |
| `cad/housing.py`, `cyclo_base.py`, `end_cap.py`, `cycloid.py` | **parametric cycloid drive** — ring / base / cap / disc+shaft (scales by `WB_RING_PINS`, `WB_MOTOR`) |
| `cad/check_cyclo.py` | asserts the disc/shaft mesh + fit the ring |
| `sim/make_mjcf.py`, `sim/view.py` | MuJoCo sim built from the build123d STLs |
| `sim/bend_model.py`, `slicer.py`, `render.py` | forward model + "slicer" toolchain |
| `sim/drive_model.py` | drive / driver-current sizing (`make drive`) |
| `sim/clearance.py`, `sim/plan.py` | clearance-aware motion planner + whole-path verify |
| `feeder-gear.scad`, `stepper-adapter.scad` | MIG-feeder motor swap (still OpenSCAD) |
| `PLAN.md`, `README.md`, `docs/DRIVE_SIZING.md` | docs (roadmap / overview / drive sizing & scaling) |

## Generated — gitignored, never edit, reproduce from source

| Path | Made by |
|---|---|
| `build/*.stl`, `build/*.step` | `py/bin/python cad/<part>.py` |
| `sim/meshes/*.stl`, `sim/wirebender.xml` | `cd sim && ../py/bin/python make_mjcf.py` |
| `sim/preview/*.png` | render scripts |

If a file is under `build/`, `sim/meshes/`, or is `sim/wirebender.xml`, it is
**generated** — delete it freely; it comes back from the source above.

## Regenerate / view
```sh
py/bin/python cad/base.py            # -> build/base.{stl,step}
py/bin/python cad/rothead.py         # -> build/rothead.{stl,step}
cd sim && ../py/bin/python make_mjcf.py        # -> wirebender.xml + meshes
DISPLAY=:0 ../py/bin/python view.py            # drag the `rot` slider
```

## History
The machine was prototyped in OpenSCAD, then ported to build123d for a cleaner
cantilever architecture. The legacy OpenSCAD parts and the old MuJoCo sim that
drove them have been removed; everything above is the current build123d design.

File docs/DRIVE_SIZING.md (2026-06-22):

# Drive sizing & scaling

How to size the bend drive (motor, driver, cycloid ratio, body diameter) for a target
wire, and how the parametric CAD scales to bigger machines. This is the design-explorer
knowledge behind `sim/drive_model.py`, the parametric `cad/cycloid.py` family, and the
clearance planner. **The model numbers are first-cut — calibrate against real bends.**

## Canonical machine

The **canonical bender targets 14 ga steel (1.63 mm) on the current motor** — the existing
**20:1 / Ø42 cycloid drive** with a NEMA17-class bend motor. 14 ga needs only ~0.5 N·m at
the output, so even a weak motor has large margin; this is the configuration to get fully
working first. Everything below is the **scaling path** for heavier stock — documented so
it isn't lost, not a change to the canonical machine.

Generate the canonical drive (defaults): `make cyclo-drive` (or `make cycloid` / `make check-cyclo`).

## The two limits that decide a job

`sim/drive_model.py` (`make drive`) answers *"what stock can this machine bend?"* from two
independent limits — a job is makeable only if it clears **both**:

1. **Torque (motor side).** Required output torque grows as **d³**:
   `required = BEND_PROCESS_FACTOR · σy · Z_plastic`, with `Z = d³/6` (solid round) or
   `(d_o³−d_i³)/6` (tube). Available = `motor_torque · usable_frac · ratio · efficiency`.
   A stepper has **no overload margin** — exceed it and it stalls/skips.
2. **Capacity (printed-disc side).** The output torque reacts through the 6 carrier
   rollers; the roller→disc-hole **bearing stress** must stay under the print material's
   allowable. Face width (`DISC_FACE_W · N_DISCS`) is the linear lever; bigger body Ø moves
   the rollers out (more lever) for more capacity.

Key finding across all our cases: **the machine is motor-bound, not disc-bound.** The
PA-CF disc is good to ~Ø7.6 mm while the motor caps you far below that — so torque/ratio is
the lever, and the cycloid stands up to the load as designed.

## Stepper torque is set by CURRENT (driver sizing)

Holding torque is quoted **at the motor's rated current** and scales ~linearly with phase
current below that, then saturates. So the **driver** — both its set point and its max
capability — delivers the torque, not the motor's physical size. `drive_model.py` works
back from a target wire to the **phase current** it needs, hence the **driver class**:

| driver | usable phase current |
|---|---|
| A4988 | ~1.0 A |
| DRV8825 / TMC2209 | ~1.7 A |
| TB6600 | ~3.5 A |
| DM542 / TMC5160 | ~4.0 A |
| DM860 / closed-loop | ~6.0 A |

**Stall taxonomy** (diagnose every stall this way):
- **Current-deficiency** — required current ≤ motor's rated current but the driver is set
  below it → *raise the current* (and check the driver can source it). A big motor starved
  of current makes a fraction of its torque; it can be weaker than a small motor run right.
- **Motor-insufficiency** — required current exceeds the motor's rated current → no driver
  setting helps; need a **bigger motor or more ratio**.

> Bench evidence: the 0.150″ stall was current-deficiency (that wire needs ~1.6 A; the
> driver was set below it). 1/4″ on the same motor is motor-insufficiency.

### Worked motor examples (20:1 drive, mild steel σy≈400)

| motor | rated | output @ rated | max bendable | notes |
|---|---|---|---|---|
| pancake NEMA17 | 0.22 N·m | ~2.5 N·m | ~Ø2.8 mm | the original weak link |
| NEMA17 hi-torque | 0.65 N·m @ 2 A | ~7.3 N·m | ~Ø4.1 mm | 0.150″ needs ~1.6 A (1.23× margin) |
| NEMA23 | 2.4 N·m @ 4 A | ~27 N·m | ~Ø6.3 mm | 1/4″ mild at the ragged edge (needs ~4.06 A vs 4 A rated) |

Phase current needed (20:1, mild): 14 ga ≈ 0.1 A · 0.150″ ≈ 1.6 A · 1/4″ ≈ 7.5 A. The 1/4″
figure exceeds any single NEMA23 → it's a ratio/body problem, not a current one.

`make drive CURRENT=1.5` shows what a given driver setting bends;
`../py/bin/python sim/drive_model.py --rated-torque 2.4 --rated-current 4` specs a motor.

## Scaling the cycloid: ratio delivers torque, diameter houses it

**A bigger body does NOT increase delivered torque** (that's motor × ratio). It increases
**capacity** and lets you fit **more ratio** while keeping the lobes full-strength. To bend
heavier wire you need **more ratio**; the body diameter then follows.

Single-stage ratio = ring-pin count (carrier fixed). Keeping the Ø3 pins at constant
spacing (so **lobe size/shape is preserved**), the body grows ~linearly with ratio:

| 1/4″ stock | σy | margin | ratio | ring pins | **body Ø** | disc margin |
|---|---|---|---|---|---|---|
| mild | 400 | 1.5× | 30:1 | 31 | **~Ø62** | 2.6× |
| mild | 400 | 2.0× | 41:1 | 41 | ~Ø81 | 3.5× |
| medium | 600 | 1.5× | 46:1 | 46 | ~Ø90 | 2.7× |
| hard | 800 | 1.5× | 61:1 | 61 | ~Ø118 | 2.7× |

(Today's drive is Ø42 / 20:1.) **σy is the wild card** — diameter scales ~(400/σy)^⅓, so
pin down the actual wire temper before committing.

**The big win — keeping lobe size + eccentricity (E=0.625) fixed means the entire eccentric
core is reused unchanged.** Only the ring and disc grow radially:

| part | 20:1 (Ø42) | 30:1 (Ø60) | |
|---|---|---|---|
| ring pins / disc lobes | 20 / 19 | 30 / 29 | grows |
| pin pitch / ring OD / disc OD | 18.5 / Ø42 / Ø35 | 27.7 / Ø60 / Ø53 | grows |
| **lobe shape, E** | 0.625 | 0.625 | **identical** |
| **eccentric shaft + Ø8 journals** | — | — | **reused** |
| **bearings 8×12, 7×13, 30×37** | — | — | **reused** |
| **disc bore Ø12 / 6× Ø5 carrier rollers** | — | — | **reused** |

### Parametric generation

`cad/housing.py` and `cad/cycloid.py` are parametric on **ring-pin count** (`N_PINS`, env
`WB_RING_PINS`); `cad/cyclo_base.py` on **motor** (`WB_MOTOR` = `nema17`/`nema23`);
`cad/end_cap.py` follows the ring OD. The eccentric core (`cycloid.eccentric_shaft`) and the
Ø37 output-bearing seat (added to `housing.py`) stay fixed so the shaft + bearings carry over.

```bash
make cyclo-drive PINS=30 MOTOR=nema23   # complete scaled drive: ring+disc+shaft+base+end_cap + fit-check
make check-cyclo PINS=30                # confirm the disc meshes the scaled ring
```

Default (`nema17`, 20 pins) is byte-identical to the validated drive. `PINS=30 MOTOR=nema23`
→ Ø60.5 ring, 29-lobe disc, Ø56.4 NEMA23 base, Ø50 cap — all watertight, mesh-checked.

### Caveats (this is NEW geometry — verify on a print)

- The **output-bearing seat** (Ø37 step at the ring base) is a design call for reusing the
  30×37 bearing in a bigger bore — sanity-check on hardware.
- NEMA23 csk just kisses the plate edge (~0.4 mm); the Ø60 ring overhangs the 56.4 plate
  ~2 mm/side (centrally supported on the bearing, so cosmetic). Bump the plate to clean up.
- **Compound drives** trade diameter for axial length: 20:1 × 1.5 → 30:1 keeps each stage
  ~Ø42–50 + a second disc set. Footprint-constrained → compound; simplicity → bigger body.
- **The pin & mandrel carry the full reaction** (27–55 N·m for 1/4″). Steel pins + a stout
  mandrel, or the body torque is wasted — see the `bend_disc.py` design notes (the mandrel
  is the strength-constrained pin).

## Clearance-aware motion planner

`sim/clearance.py` + `sim/plan.py` choose collision-safe moves for G-code:

- **`clearance.py`** — ground-truth bend-cell clearance. Exact body poses from the MuJoCo
  model, distances measured against the **real non-convex STL meshes** via scipy KD-trees
  over surface samples (MuJoCo's own collision convexifies meshes → too coarse; trimesh
  `signed_distance`/rtree segfaults under planner call volume). Convention: the formed wire
  is fixed, the head orbits it. Excludes the fixed die exit (`end_cap`, the `arbor_mount`
  placeholder, the mandrel-wrap region) so it flags only *avoidable* swing/rotation hits.
- **`plan.py`** — per bend, picks the head-rotation direction (short vs **long-way
  backtrack**) by worst-case clearance over the swept path, and searches a **feed-advance**
  when both directions foul the formed part. `plan.verify()` is the whole-path safety gate:
  it replays the *entire* interpolated motion through the clearance model and fails if any
  frame dips below margin (catches greedy-planner traps).
- **Visualize:** `make anim-view NAME=chair ARGS=--plan` (or `make anim … ARGS=--plan` for a
  GIF) animates the planned moves with the wire coloured by live clearance (green/amber/red).

**Caveats:** ~1–2 mm sampling resolution (keep margin); pin-vs-part during the bend stroke
is still the parametric `interference.py` rule (no bend-disc mesh in the sim yet).

## Homing (conventions decided; hardware/CAD pending)

Open-loop steppers lose position on a stall, so homing is needed to re-reference. Two
switches (feed/Axis 1 is relative — no home). The home zeros equal the software zeros the
forward model + planner already use (`machine.py`: `ROT_HOME_DEG`, `BEND_HOME_DEG`):

- **Axis 2 (tube rotation / bend plane) — `tube_rot = 0` = mandrel / bend-disc axis pointing
  UP (+Z)** with the wire along X on the XY deck (a bend at home lies in the horizontal
  plane). Flag on the rotating head → fixed switch on the upright. Rotation sets the bend
  PLANE, so ~1° home repeatability suffices (a ramped microswitch is fine).
- **Axis 3 (bend die) — `bend = 0` = bend PIN 90° orthogonal to the wire axis** (the sweep
  start; the die sweeps to `DIE_TRAVEL_DEG` from here). **Must home on the cycloid OUTPUT** —
  the 20:1 makes the motor turn ~15× over the 270° output, so a motor-shaft index is
  ambiguous. Flag on the rotating output (ring/disc) → fixed sensor on the end_cap/base.
  This sets the bend-zero, so favour an **optical/hall** (non-contact) sensor; the 20:1
  reduction gives sub-degree output accuracy from a modest flag.
- **Hardware: microswitches.** Axis 3 — a radial **home tab on the rotating ring**
  (`arbor_mount.py` `HOME_FLAG`, tune `HOME_FLAG_ANGLE` to the pin-orthogonal home) presses
  a switch on the fixed `end_cap`/`cyclo_base`. Axis 2 — a tab on the head presses a switch
  on the upright (head tab pending the head redesign). Both use the adjustable bracket
  `cad/home_switch.py` (subminiature SS-5GL/D2F switch, slotted M3 mounts to trim the trip
  onto the software zero; GRBL pull-off `HOME_PULLOFF_DEG`).
- Touches: `machine.py` (home zeros, pull-off, travel — done) · CAD (`arbor_mount` tab +
  `home_switch` bracket — done; head tab pending) · GRBL (homing cycle). **Closed-loop
  steppers** additionally *detect* skips and recover — the robust endgame given the stalls.
- **Visualize:** `make home` (GIF) / `make home-view` (live) — `sim/home.py` simulates the
  homing cycle (seek → trip → pull-off → zero) and the switch (bracket + body + lever, placed
  in the MuJoCo model at the ring flag's home) so you can see the position + mounting and
  confirm the homed pose (mandrel +Z, pin ⊥ wire).

## Toward a reusable kinematic kernel (3rd-party tools)

So others can build slicers/G-code tools on this machine, the plan mirrors robotics
(URDF + MoveIt) and 3D-printing (Cura profiles): a **declarative, versioned machine profile
(`machine.json`)** as the public contract, generated from `machine.py`, plus a **stable
kernel API** (`forward`, `capabilities`, `clearance`, `plan`) with a thin **JSON-RPC/CLI
boundary** so non-Python tools can call it. The MJCF (`sim/wirebender.xml`) is the ready-made
URDF-equivalent geometry/collision model. Build the planner/clearance first (done), then
lift the validated code into the kernel shape.

## Calibration TODO (before trusting predictions on hardware)

- `BEND_PROCESS_FACTOR` (1.6) — fit to measured stall torque vs ideal plastic moment.
- `MATERIALS` bearing allowables + `PEAK_CARRIER_SHARE` (0.5) — fit to real disc wear.
- Wire **σy** by temper — the dominant lever on every number above.
- Clearance sampling vs real fit; tube model needs mandrel/wiper wrinkle + ovalization.

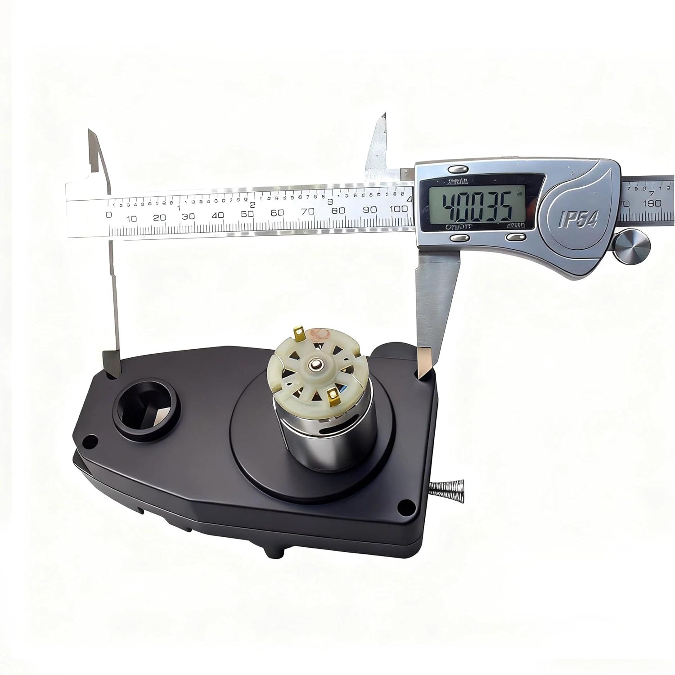
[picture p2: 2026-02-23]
reference-images/717+hNLel3L._SL1500_.jpg

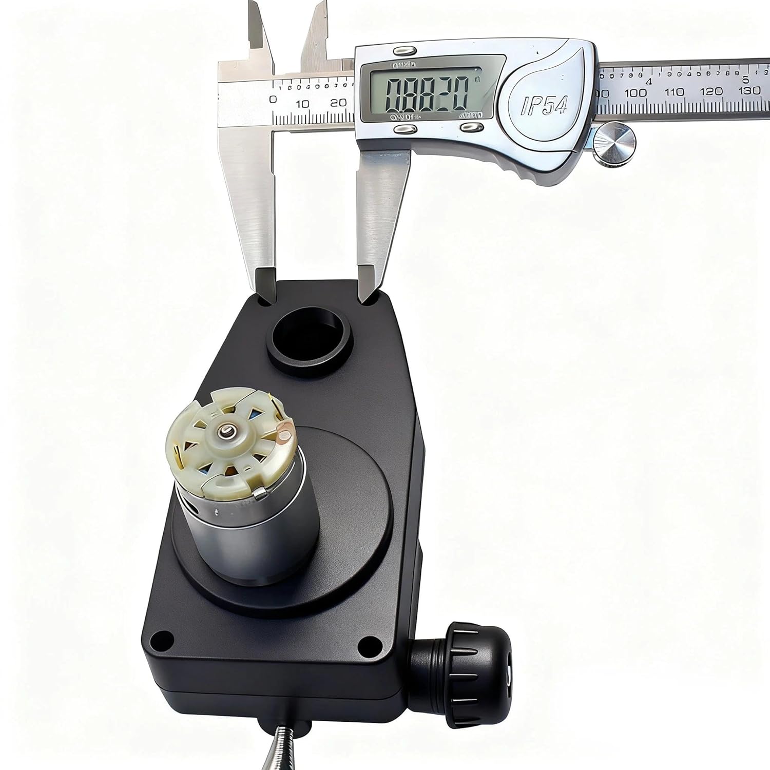
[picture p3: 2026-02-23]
reference-images/71c5lm3K0AL._SL1500_.jpg

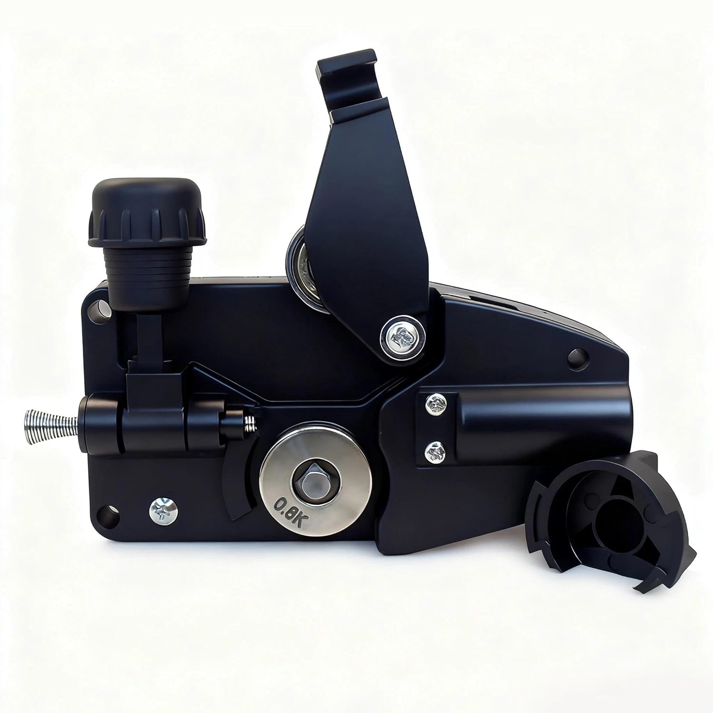
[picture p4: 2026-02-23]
reference-images/71SzKdkqZYL._SL1500_.jpg

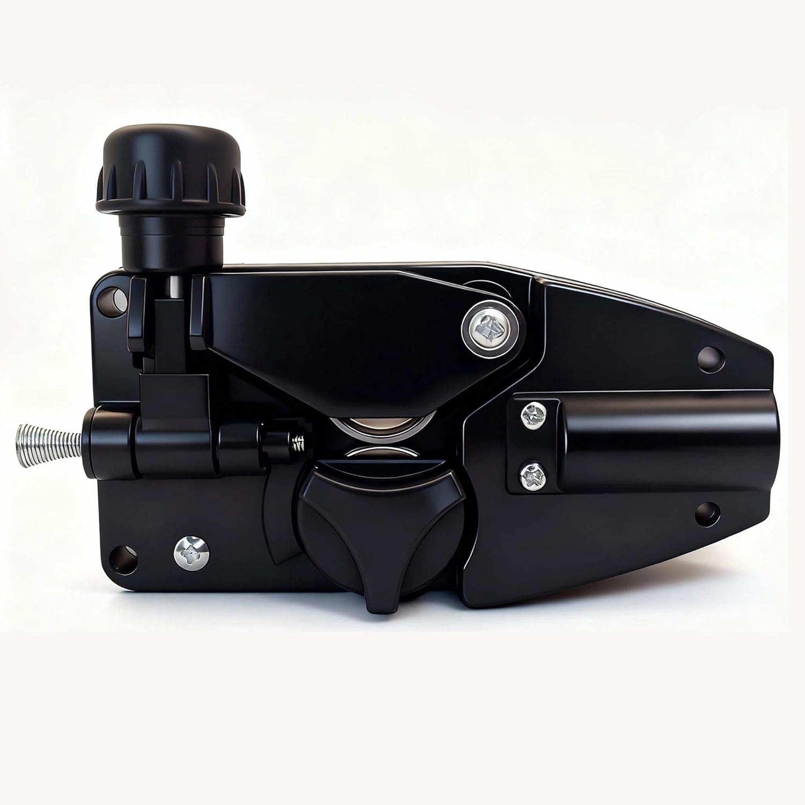
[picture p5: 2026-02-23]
reference-images/61OPxaKCTEL._SL1500_.jpg

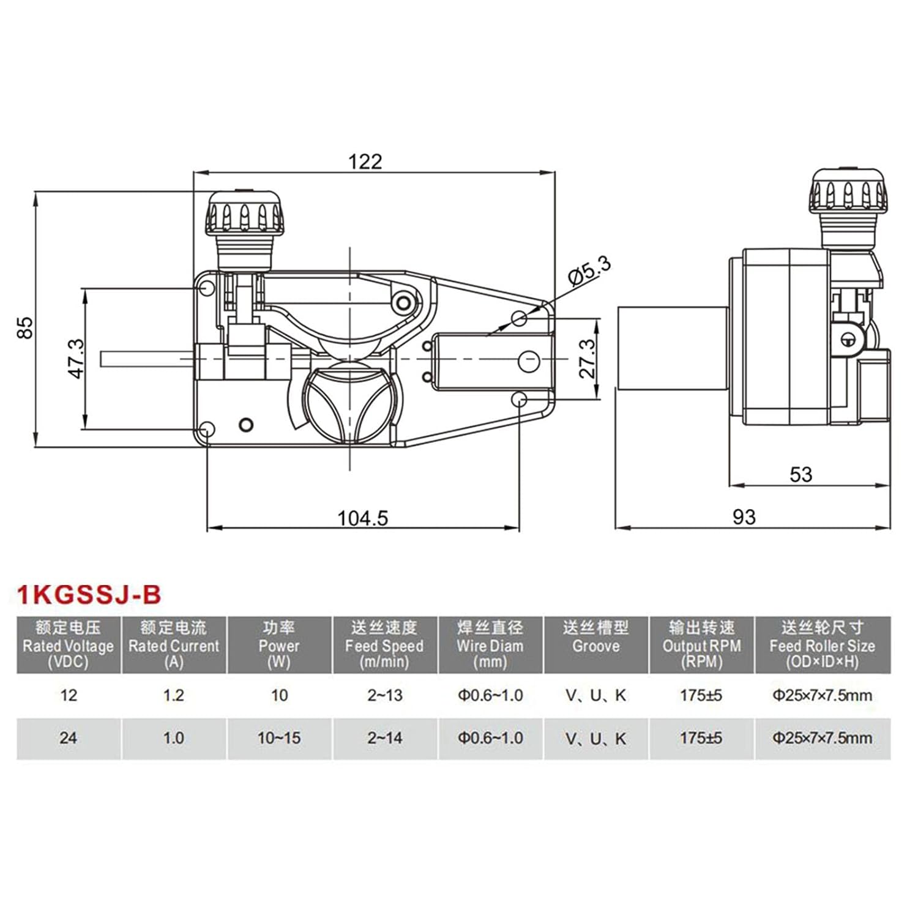
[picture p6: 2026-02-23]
reference-images/61Zm12CS5aL._SL1500_.jpg

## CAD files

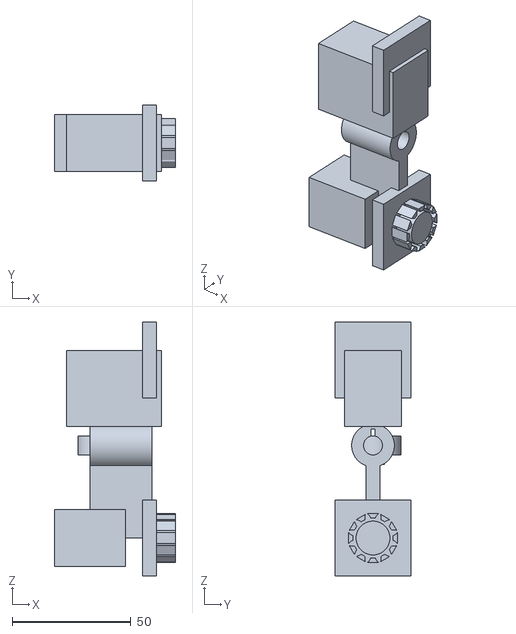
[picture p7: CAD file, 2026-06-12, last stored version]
build/rothead_assembly.stl
51.0 x 32.0 x 107.0

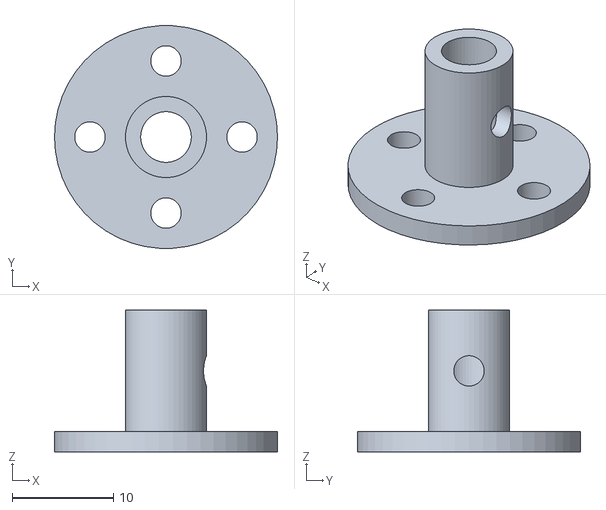
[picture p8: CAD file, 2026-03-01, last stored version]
motor-flange.stl
22.0 x 22.0 x 14.0

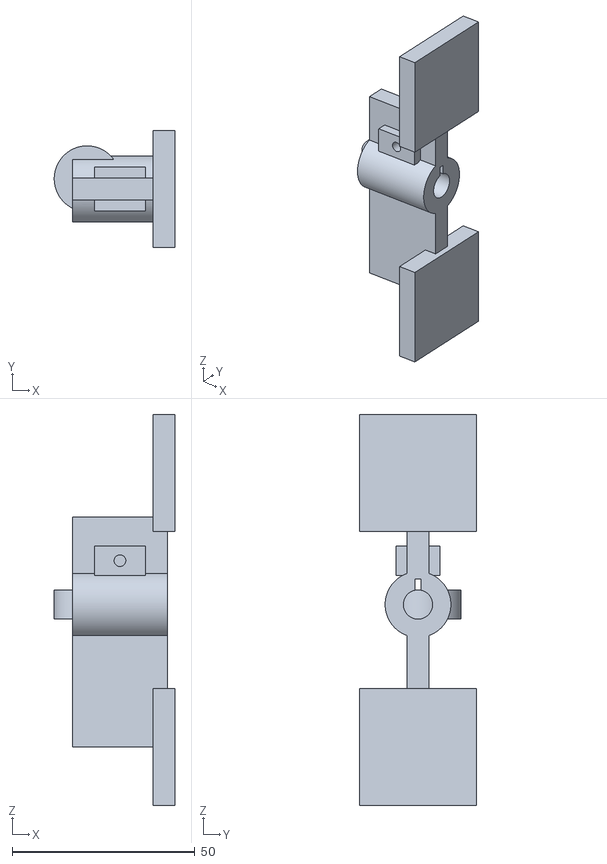
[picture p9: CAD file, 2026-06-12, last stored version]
sim/meshes/head_v2.stl
33.0 x 32.0 x 107.0

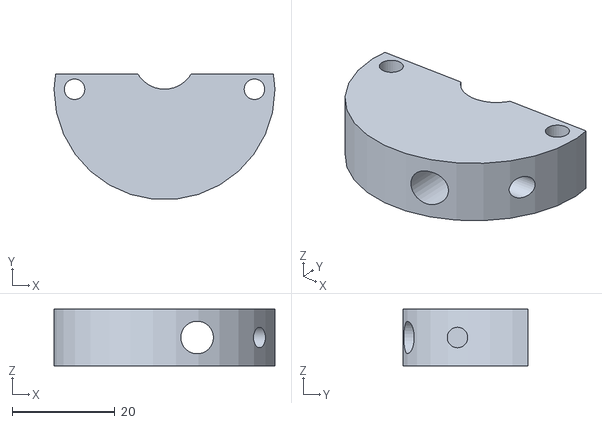
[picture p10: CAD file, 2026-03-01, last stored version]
bender-head.stl
43.0 x 24.4 x 11.0

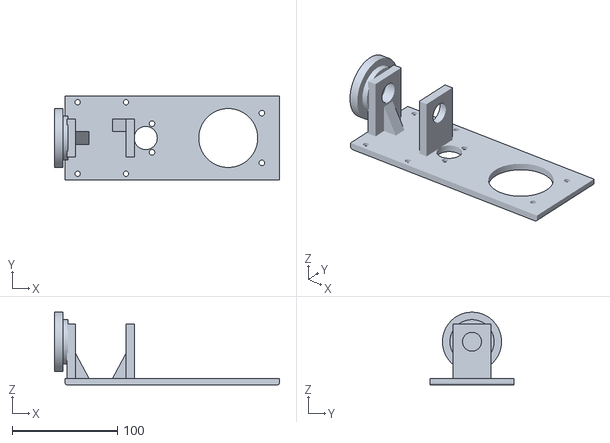
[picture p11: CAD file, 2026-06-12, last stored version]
sim/meshes/base_v2.stl
214.0 x 80.0 x 69.1

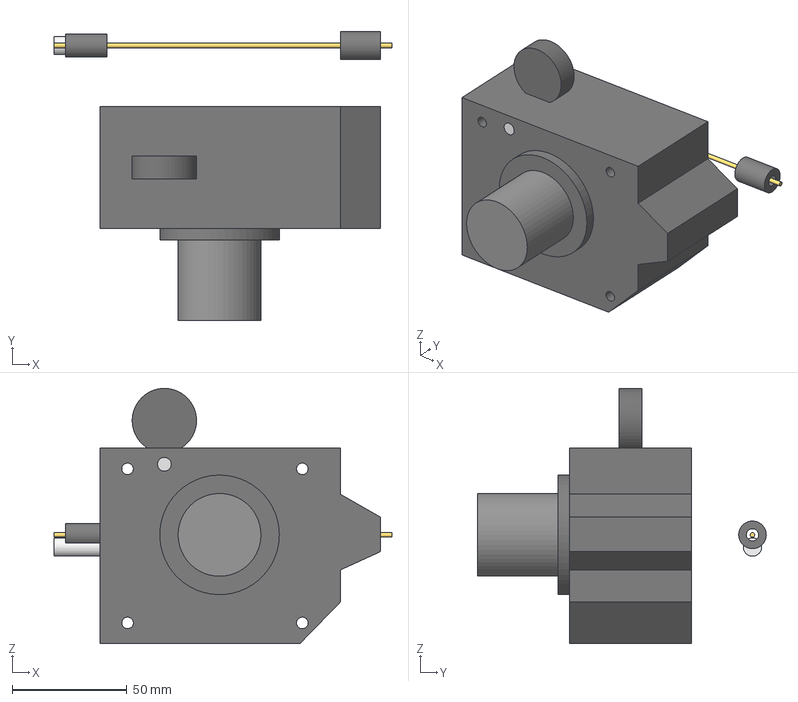
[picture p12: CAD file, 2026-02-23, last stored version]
wire_feed.step
147.0 x 125.5 x 111.0 mm
housing
output_nozzle
inlet_fitting
wire_feed_axis
gearbox_flange
motor
drive_roller
tensioner_roller
tensioner_arm
arm_pivot_pin
tensioner_knob
tension_adj_bolt

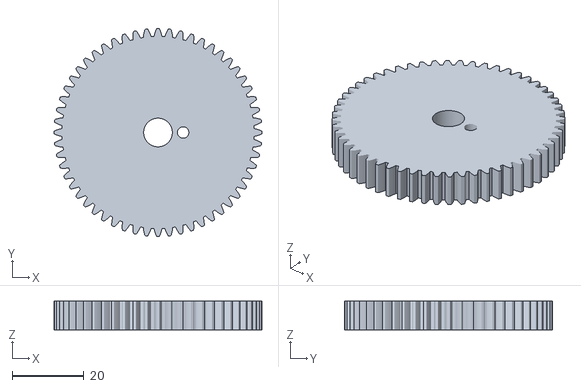
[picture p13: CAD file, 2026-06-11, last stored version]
sim/meshes/bend_gear.stl
58.0 x 58.0 x 8.00

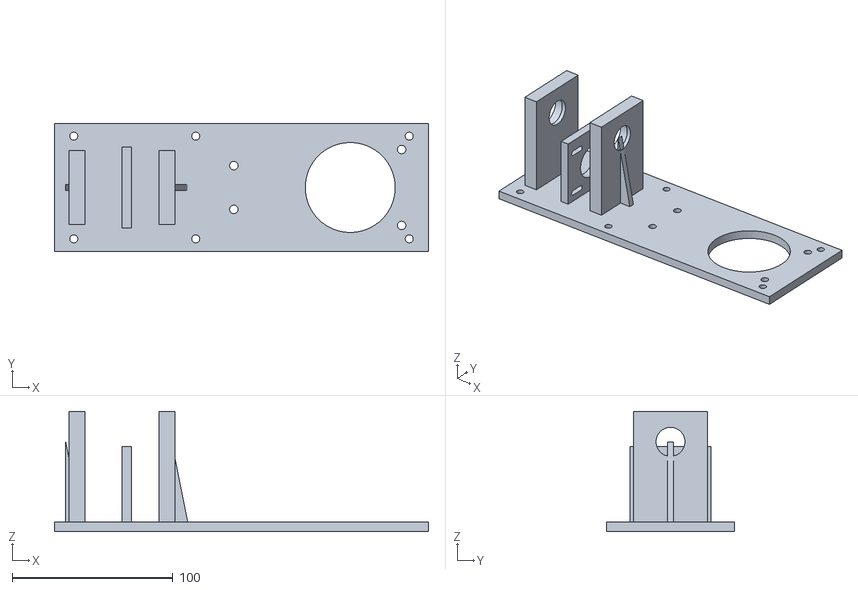
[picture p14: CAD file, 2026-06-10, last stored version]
sim/meshes/bracket.stl
233.0 x 80.0 x 75.0

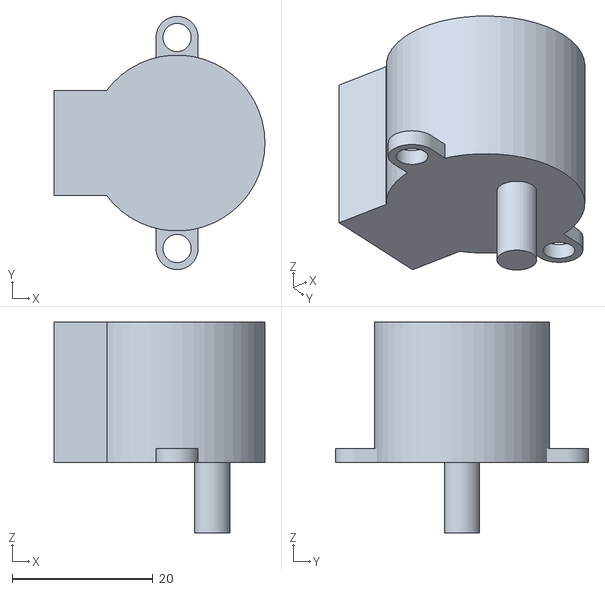
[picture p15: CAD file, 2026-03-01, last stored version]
build/motor.scad.stl
30.0 x 36.0 x 30.0

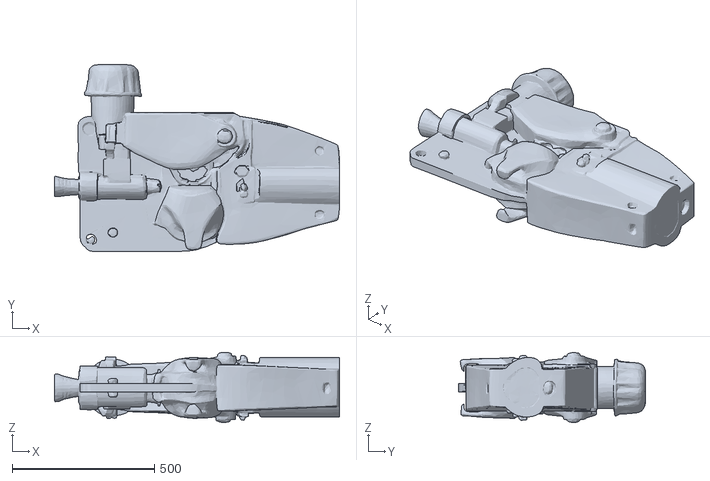
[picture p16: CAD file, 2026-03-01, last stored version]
build/extruder.converted.stl
1000.7 x 655.7 x 246.5

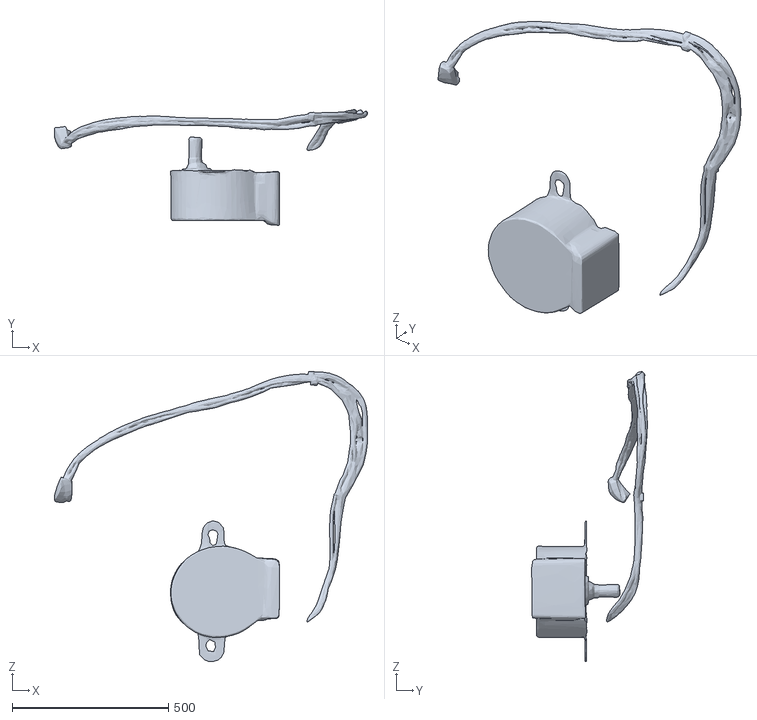
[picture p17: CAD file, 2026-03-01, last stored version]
build/motor.converted.stl
1000.3 x 369.7 x 928.0

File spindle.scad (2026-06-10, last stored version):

// spindle.scad
// The rotating spindle (Axis 2 — bend direction). It rides in the two 608
// bearings of base-bracket.scad, carries the 60T GT2 pulley, and presents a
// front flange that the bending-head adapter bolts to. The wire passes through
// the Ø4 bore (PTFE-lined). Print axis-vertical (as modelled) so the bearing
// journals come out round — an 8 mm metal tube/rod bored 4 mm is better for the
// journals if you have it; this models the full part for fit/reference.
//
// Frame: Z = spindle axis, z = 0 at the front-flange face (head end), increasing
// toward the rear (feeder). Z positions are derived from base-bracket.scad —
// keep the shared block in sync.

show = "spindle";        // "spindle" | "assembly"
$fn = 96;

// ── shared with base-bracket.scad (keep in sync) ────────────────────
BRG_OD = 22;  BRG_W = 7;  BRG_BORE = 8;     // 608 bearing
BORE   = 4;                                  // wire bore
FLANGE_X = -19;                              // bracket X of the front-flange face
FRONT_X  = 0;   REAR_X = 56;                 // bracket X of the bearing centres
PULLEY_X = 28;  PULLEY_OD = 40;  PULLEY_W = 8;   // 60T GT2 pulley

// ── derived axial stations (z = bracket_X − FLANGE_X) ───────────────
Z_FRONT_BRG = FRONT_X - FLANGE_X;            // 19
Z_PULLEY    = PULLEY_X - FLANGE_X;           // 47
Z_REAR_BRG  = REAR_X  - FLANGE_X;            // 75
Z_REAR_END  = Z_REAR_BRG + 14;               // 89  (rear stub for the wire entry)

// ── spindle dimensions ──────────────────────────────────────────────
JOURNAL   = BRG_BORE;        // 8 mm — bearing bore / pulley seat
SHOULDER  = 11;              // shoulder OD that axially locates the bearings
FLANGE_OD = 32;  FLANGE_T = 6;
FLANGE_BOLT = 22;            // head-adapter bolt circle
FLANGE_HOLE = 3.2;          // M3 clearance
FLAT_DEPTH  = 0.6;          // set-screw flat on the pulley seat

module seg(d, z0, z1) translate([0, 0, z0]) cylinder(d = d, h = z1 - z0);

module spindle() {
    difference() {
        union() {
            seg(FLANGE_OD, 0, FLANGE_T);                                    // front flange
            seg(SHOULDER,  FLANGE_T, Z_FRONT_BRG - BRG_W/2);                // front shoulder
            seg(JOURNAL,   Z_FRONT_BRG - BRG_W/2, Z_FRONT_BRG + BRG_W/2);   // front journal
            seg(SHOULDER,  Z_FRONT_BRG + BRG_W/2, Z_PULLEY - PULLEY_W/2);   // mid
            seg(JOURNAL,   Z_PULLEY - PULLEY_W/2, Z_PULLEY + PULLEY_W/2);   // pulley seat
            seg(SHOULDER,  Z_PULLEY + PULLEY_W/2, Z_REAR_BRG - BRG_W/2);    // mid
            seg(JOURNAL,   Z_REAR_BRG - BRG_W/2, Z_REAR_BRG + BRG_W/2);     // rear journal
            seg(JOURNAL,   Z_REAR_BRG + BRG_W/2, Z_REAR_END);              // rear stub
        }
        // wire bore through the whole length
        seg(BORE, -1, Z_REAR_END + 1);
        // head-adapter bolt holes in the flange
        for (i = [0:3]) rotate([0, 0, 90*i + 45])
            translate([FLANGE_BOLT/2, 0, -1]) cylinder(d = FLANGE_HOLE, h = FLANGE_T + 2);
        // set-screw flat on the pulley seat (so the GT2 pulley grub screw bites)
        translate([JOURNAL/2 - FLAT_DEPTH, -PULLEY_W/2 - 1, Z_PULLEY - PULLEY_W/2])
            cube([5, PULLEY_W + 2, PULLEY_W]);
    }
}

// ── reference ghosts (bearings + pulley at their seats) ─────────────
module ghost() {
    for (z = [Z_FRONT_BRG, Z_REAR_BRG]) color("0.3 0.3 0.32", 0.5)
        translate([0, 0, z - BRG_W/2]) difference() {
            cylinder(d = BRG_OD, h = BRG_W);
            translate([0, 0, -1]) cylinder(d = BRG_BORE, h = BRG_W + 2);
        }
    color("0.15 0.16 0.18", 0.55)
        translate([0, 0, Z_PULLEY - PULLEY_W/2]) difference() {
            cylinder(d = PULLEY_OD, h = PULLEY_W);
            translate([0, 0, -1]) cylinder(d = JOURNAL, h = PULLEY_W + 2);
        }
}

color([0.7, 0.72, 0.76]) spindle();
if (show == "assembly") ghost();

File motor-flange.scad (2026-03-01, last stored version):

$fn = 50;

flange_thickness = 2;

module setscrew() {
    cylinder(d = 3, h = 10);
}

module flange() {
    f_od = 22;  // overall dia
    bcd = 15;   // bolt circle dia
    f_t = 2;    // flange thickness
    h_id = 3;   // bolt hole ID
    id = 5;     // bore ID
    
    difference() {
        cylinder(d = f_od, h = f_t);
        // bolt circle
        for(i = [0:3]) {
            angle = 360/4*i;
            echo(angle);
            rotate([0, 0, angle]) translate([bcd/2, 0]) cylinder(d = h_id, h = f_t);
        }
        // bore
        cylinder(h=f_t, d = id);
    }
}

module barrel() {
    id = 5;
    od = 8;
    l = 12; // hub barrel length
    difference() {
        cylinder(h = l, d = od);
        cylinder(h = l, d = id);
        translate([0,0, l/2]) rotate([0, 90]) setscrew();
    }
}

flange();
translate([0, 0, flange_thickness]) barrel();

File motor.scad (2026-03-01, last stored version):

$fn = 50;

bolt_pattern = 30;
diameter = 25;
height = 20;

module flange() {
        
    difference() {
        linear_extrude(2) hull() {
            translate([0, -bolt_pattern/2]) circle(d=6);
            translate([0, bolt_pattern/2]) circle(d=6);
        }
        translate([0, -bolt_pattern/2]) cylinder(d=4, h=2);
        translate([0, bolt_pattern/2]) cylinder(d=4, h=2);
        
    }
}

module shaft() {
    translate([5, 0, -10]) cylinder(h = 10, d = 5);    
}

module body() {
    cylinder(h = height, d = diameter);
}   

module wiring_block() {
    translate([-diameter/2,0, height/2]) cube(center=true, [10, 15, height]);
}

flange();
shaft();
body();
wiring_block();

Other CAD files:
build/rothead.step
build/base.step
build/motor-flange.scad.stl
build/bender-head.scad.stl
sim/meshes/bender-head.stl
sim/meshes/motor.stl
sim/meshes/motor-flange.stl
stepper-adapter.scad
base-bracket.scad
base.scad
bend-gears.scad
bender-head.scad
build/assembly_view.scad
feeder-gear.scad
head.scad
massing.scad
rothead.scad
sim/meshes/head.stl

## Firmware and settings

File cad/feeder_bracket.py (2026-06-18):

"""feeder_bracket.py — flat upright plate that holds the wire feeder VERTICALLY.

The feeder (1KGSSJ-B) used to lie flat on the deck, bolted down through its 4-hole pattern
(FEEDER_BOLT_SPAN x FEEDER_BOLT_W1/W2) with two boss clearances (the Ø56 motor bulge and
the Ø24 nose) opening through the deck. We now stand the feeder up on its side against this
flat plate, so its wire output emerges horizontally on the machine centre.

It is just a flat plate — no foot, no gussets. It bolts to the base plate the same way the
bearing uprights do: M3 heat-set inserts in its BOTTOM EDGE (z=0), screws coming up from
under the deck (the deck carries the matching clearance + counterbore).

The plate carries the WHOLE feeder hole set the deck used to, rotated 90° into the vertical
face (local x = the SPAN direction, nose at -X; the bolt widths run up the wall in Z):
  - 4 feeder mounting holes -> M5 clearance THROUGH holes in the face (bolt + nut on the back)
  - the nose boss clearance (Ø24) bored through the wall along Y so that protrusion passes through.

The LARGER (motor Ø56) boss is no longer a through-hole. We mount the drive NEMA17 directly
to the plate there, so that boss region becomes a sandwich (with BOSS_BACK, the default):
  - +Y (CENTRE face, feeder side): a round Ø56 pocket so the feeder seats flat, plus routed
    head-clearance + countersinks along the slots so the motor-screw heads clear here too.
  - MID-PLANE: a 2.5mm web carrying a SLOTTED NEMA17 pattern (4 bolt slots + a centre
    pilot/shaft slot). The motor screws come in from the centre face into the motor's tapped
    face; sliding it along the slots sets the pinion/feeder-gear mesh, and the surrounding
    full-thickness plate keeps the thin web from flexing.
  - −Y (FORWARD/outer face): a chamfered pocket that recesses the NEMA17 body and clears its
    Ø22 pilot boss; the motor faces forward, accessible.
The motor sits on the −Y face, its shaft/pinion reaching through the web into the centre-side
boss pocket to mesh with the feeder gear. (The cutter is authored boss-front and mirrored
about the mid-plane when BOSS_BACK; flip BOSS_BACK to swap the two faces.)

Placement the assembly applies (drawn here with the −Y/forward face at y=0):
  - mounting face on the −Y edge at FACE_Y (−35mm); the feeder hangs on the +Y (centre) side
    and its output (35mm off the face) lands on the centreline y=0.
  - bolt-pattern lengthwise centreline (= feeder output / wire axis) at CENTER_Z (30mm)
    above the deck top -> wire axis at (y=0, z=30).

    py/bin/python cad/feeder_bracket.py   ->  build/feeder_bracket.stl
"""
import math
import os
import sys

HERE = os.path.dirname(os.path.abspath(__file__))
sys.path.insert(0, HERE)
from build123d import (Align, Axis, Box, BuildPart, BuildSketch, Cylinder, Plane, Pos,
                        SlotOverall, chamfer, export_stl, loft, mirror)
from base import (FEEDER_BOLT_SPAN, FEEDER_BOLT_W1, FEEDER_BOLT_W2, FEEDER_HOLE,
                  FEEDER_X, FEEDER_MOTOR_X, FEEDER_MOTOR_HOLE, FEEDER_NOSE_X, FEEDER_NOSE_HOLE,
                  INSERT_D as M3_INS_D, INSERT_H as M3_INS_H,    # 4.6 / 5.0 — same M3 inserts the uprights use
                  FEEDER_BR_FACE_Y as FACE_Y, FEEDER_BR_T as WALL_T, FEEDER_BR_INS_X as BASE_INS_X,
                  AXIS_Z)

# ── placement the assembly applies (documented; used by the sim later) ──
# FACE_Y, WALL_T, BASE_INS_X come from base.py (deck mount is the single source).
CENTER_Z = AXIS_Z      # bolt-pattern centreline = the wire axis (single source: base.AXIS_Z)

# ── feeder mounting pattern, rotated into the vertical face (local x=span, z=width) ──
SPAN = FEEDER_BOLT_SPAN                       # 104.5 along X
# nose end (-X) carries the narrow width, motor end (+X) the wide one (see base.FEEDER_HOLES)
HOLES = [(-SPAN / 2,  CENTER_Z + FEEDER_BOLT_W2 / 2),
         (-SPAN / 2,  CENTER_Z - FEEDER_BOLT_W2 / 2),
         ( SPAN / 2,  CENTER_Z + FEEDER_BOLT_W1 / 2),
         ( SPAN / 2,  CENTER_Z - FEEDER_BOLT_W1 / 2)]

# ── motor-boss centre (local), shared by the front pocket / web / back pocket ──
MOTOR_X = FEEDER_MOTOR_X - FEEDER_X           # +20.25 — large boss / NEMA17 axis
NOSE_X = FEEDER_NOSE_X - FEEDER_X             # -36.25 — small (nose) boss, plain through-bore

# ── integrated NEMA17 mount at the motor boss ──────────────────────────
NEMA_BOLT = 31.0          # NEMA17 square bolt pitch -> holes at ±15.5
NEMA_BODY = 42.3          # NEMA17 body square (back-pocket clearance footprint)
NEMA_PILOT = 22.0         # centring pilot-boss Ø (the centre slot must clear it + the shaft/pinion)
M3_CLEAR = 3.4            # motor-screw clearance (M3)
M3_CSK = 6.0             # M3 flat-head countersink major Ø (90°), opening on the boss/front side
HEAD_CLEAR = 7.5         # routed channel Ø for the screw head to slide in (0.75mm radial past the Ø6 head edge)
WEB_T = 2.5              # mounting web at the plate mid-plane (0.5mm into each pocket vs the original 1.5)
PILOT_CLEAR = 0.5        # clearance around the pilot boss in the centre slot
POCKET_CLEAR = 1.0       # clearance around the NEMA body in the back pocket
NEMA_CHAMFER = 6.0       # 45° corner chamfer on the motor pocket, matching the stepper body -> room at the corners
BOSS_BACK = True         # feeder boss + screw heads on the +Y (centre) face, motor pocket on the −Y (forward/outer) face
SLOT_TRAVEL = 12.0       # mesh-adjust slide range -> slots are this much longer than the bore (±6mm)
SLOT_OFFSET = 3.0        # shift the motor pattern (slots + pilot + back pocket) this far along +SLOT_DIR ("back")
SLOT_DIR = (1.0, 0.0)    # slide direction in the face plane (dx, dz); (1,0)=along X. one-line to rotate.

# ── plate body ──
EDGE_MARGIN = 12.0
HALF_X = SPAN / 2 + EDGE_MARGIN               # 64.25 -> plate width 128.5
WALL_H = CENTER_Z + FEEDER_BOLT_W1 / 2 + EDGE_MARGIN   # 65.65, top above the highest hole
# WALL_T (plate thickness) and BASE_INS_X (bottom-edge mount spacing) come from base.py.

_C, _MIN = Align.CENTER, Align.MIN


def _ybore(d, h, x, z, y0):
    """Cylinder Ø d, length h, drilled along +Y starting at y=y0, centred at (x, z)."""
    c = Cylinder(d / 2, h, align=(_C, _C, _MIN)).rotate(Axis.X, -90)   # base at origin, axis +Y
    return Pos(x, y0, z) * c


def _yslot(d, h, x, z, y0, travel, ang_deg):
    """Capsule (obround) hole Ø d bored along +Y, length h from y=y0; the bore centre is
    swept `travel` along a line at ang_deg from +X in the face (X-Z) plane, centred at (x, z)."""
    cap = Cylinder(d / 2, h, align=(_C, _C, _C)).rotate(Axis.X, -90)   # bore along Y, centred
    shape = (Box(travel, h, d, align=(_C, _C, _C))                      # connecting bar: X long, Y=bore depth, Z=wide
             + cap.moved(Pos(travel / 2, 0, 0)) + cap.moved(Pos(-travel / 2, 0, 0)))
    shape = shape.rotate(Axis.Y, ang_deg)
    return Pos(x, y0 + h / 2, z) * shape


def _yslot_csk(d_bore, d_head, x, z, y_face, depth, travel, ang_deg):
    """Obround countersink for a slotted screw: an obround opening Ø d_head at y=y_face that
    tapers (90°) to Ø d_bore at y=y_face+depth, swept `travel` along the slot, opening toward
    −Y (the boss/front side) so a flat head sits flush in the web as the screw slides."""
    pl = Plane((0, 0, 0), x_dir=(1, 0, 0), z_dir=(0, 1, 0))         # in X-Z, normal +Y
    with BuildPart() as bp:
        with BuildSketch(pl):                                       # face: wide (head Ø)
            SlotOverall(travel + d_head, d_head)
        with BuildSketch(pl.offset(depth)):                        # depth: narrow (bore Ø)
            SlotOverall(travel + d_bore, d_bore)
        loft()
    return Pos(x, y_face, z) * bp.part.rotate(Axis.Y, ang_deg)


def _motor_mount(part):
    """Carve the integrated NEMA17 mount: a Ø56 boss pocket (+ routed head-clearance along the
    slots) on one face, a chamfered motor pocket on the other, joined by the 1.5mm slotted web.

    The cutter is built boss-on-the-FRONT (−Y), then mirrored about the mid-plane when BOSS_BACK
    so the boss + screw heads land on the +Y (centre) face and the motor pocket faces forward.
    The motor pattern slides off the (fixed) boss centre by SLOT_OFFSET."""
    yw0, yw1 = (WALL_T - WEB_T) / 2, (WALL_T + WEB_T) / 2          # web spans y = yw0..yw1
    ang = math.degrees(math.atan2(SLOT_DIR[1], SLOT_DIR[0]))
    ox, oz = SLOT_OFFSET * SLOT_DIR[0], SLOT_OFFSET * SLOT_DIR[1]
    mcx, mcz = MOTOR_X + ox, CENTER_Z + oz                        # motor / bolt-pattern centre (slid off the boss)
    bolts = [(sx, sz) for sx in (-NEMA_BOLT / 2, NEMA_BOLT / 2) for sz in (-NEMA_BOLT / 2, NEMA_BOLT / 2)]
    csk_depth = (M3_CSK - M3_CLEAR) / 2                            # 90° flat-head countersink depth
    cuts = []

    # boss-side round pocket (feeder boss clearance Ø56) — stops at the web. Stays on the BOSS
    # centre (the boss is fixed by the feeder; only the motor slides).
    cuts.append(_ybore(FEEDER_MOTOR_HOLE, yw0 + 1, MOTOR_X, CENTER_Z, -1))
    # boss-side head-clearance routed along each slot: the round boss pocket only covers the
    # centre, so the slot ends run into solid plate. Route an obround at head Ø to the web so the
    # head clears wherever the screw is parked, and countersink the slot so a flat head sits flush.
    for sx, sz in bolts:
        cuts.append(_yslot(HEAD_CLEAR, yw0 + 1, mcx + sx, mcz + sz, -1, SLOT_TRAVEL, ang))
        cuts.append(_yslot_csk(M3_CLEAR, M3_CSK, mcx + sx, mcz + sz, yw0, csk_depth, SLOT_TRAVEL, ang))
    # motor-side pocket (NEMA17 body), open to the far face; corners chamfered like the stepper body
    px = NEMA_BODY + 2 * POCKET_CLEAR + abs(SLOT_DIR[0]) * SLOT_TRAVEL
    pz = NEMA_BODY + 2 * POCKET_CLEAR + abs(SLOT_DIR[1]) * SLOT_TRAVEL
    pocket = Pos(mcx, (yw1 + WALL_T + 1) / 2, mcz) * Box(px, WALL_T + 1 - yw1, pz)
    cuts.append(chamfer(pocket.edges().filter_by(Axis.Y), NEMA_CHAMFER))   # 45° on the 4 vertical corners
    # WEB slots through full depth: centre pilot/shaft slot + 4 NEMA bolt slots
    cuts.append(_yslot(NEMA_PILOT + 2 * PILOT_CLEAR, WALL_T + 2, mcx, mcz, -1, SLOT_TRAVEL, ang))
    for sx, sz in bolts:
        cuts.append(_yslot(M3_CLEAR, WALL_T + 2, mcx + sx, mcz + sz, -1, SLOT_TRAVEL, ang))

    cutter = cuts[0]
    for c in cuts[1:]:
        cutter += c
    if BOSS_BACK:      # flip so the boss + heads are on +Y (centre) and the motor pocket faces −Y
        cutter = mirror(cutter, about=Plane((0, WALL_T / 2, 0), x_dir=(1, 0, 0), z_dir=(0, 1, 0)))
    return part - cutter


def feeder_bracket():
    # flat plate: x -HALF_X..+HALF_X, y 0..WALL_T (front face at y=0), z 0..WALL_H
    part = Pos(0, WALL_T / 2, WALL_H / 2) * Box(2 * HALF_X, WALL_T, WALL_H)
    # feeder M5 mounting holes: clearance THROUGH the plate along Y (bolt + nut on the back)
    for (hx, hz) in HOLES:
        part -= _ybore(FEEDER_HOLE, WALL_T + 2, hx, hz, -1)
    # nose boss clearance: still a plain bore through the wall
    part -= _ybore(FEEDER_NOSE_HOLE, WALL_T + 2, NOSE_X, CENTER_Z, -1)
    # large (motor) boss -> integrated NEMA17 mount (front pocket / web / back pocket)
    part = _motor_mount(part)
    # M3 base-mount inserts in the bottom edge (z=0), bored up +Z (like the base uprights)
    for sx in (BASE_INS_X, -BASE_INS_X):
        part -= Pos(sx, WALL_T / 2, 0) * Cylinder(M3_INS_D / 2, M3_INS_H, align=(_C, _C, _MIN))
    return part


if __name__ == "__main__":
    os.makedirs("build", exist_ok=True)
    part = feeder_bracket()
    export_stl(part, "build/feeder_bracket.stl")
    bb = part.bounding_box()
    import trimesh
    m = trimesh.load("build/feeder_bracket.stl")
    print(f"feeder_bracket: flat plate {2*HALF_X:.1f}x{WALL_H:.1f}x{WALL_T}  "
          f"4x M5 through Ø{FEEDER_HOLE} (feeder pattern span {SPAN}, w {FEEDER_BOLT_W1}/{FEEDER_BOLT_W2})  "
          f"+ nose boss clear Ø{FEEDER_NOSE_HOLE}  + integrated NEMA17 mount @ x={MOTOR_X:.2f}+{SLOT_OFFSET:g} "
          f"(boss Ø{FEEDER_MOTOR_HOLE} pocket + routed head clears on {'+Y centre' if BOSS_BACK else '-Y'} face / {WEB_T}mm web, "
          f"NEMA {NEMA_BOLT}mm csk slots ±{SLOT_TRAVEL/2:.0f}mm along {'X' if SLOT_DIR[1]==0 else 'Z' if SLOT_DIR[0]==0 else 'angle'} "
          f"/ motor {NEMA_BODY}mm pocket chamfered {NEMA_CHAMFER:g} on {'-Y forward' if BOSS_BACK else '+Y'} face)  "
          f"+ 2x M3 edge inserts @ x=±{BASE_INS_X}  face@y={FACE_Y} axis@z={CENTER_Z}  "
          f"bbox {[round(v,1) for v in bb.size]}  bodies:{len(m.split(only_watertight=False))}  "
          f"watertight:{m.is_watertight}")

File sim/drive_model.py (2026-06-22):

#!/usr/bin/env python3
"""drive_model.py — "what stock can THIS machine bend?" (the design explorer).

Turns the bend-drive parameters in machine.py into the two limits that decide a
bending job, so you can size a machine for a job (or a job for a machine):

  1. TORQUE to generate the bend (motor side):
       required = process_factor · σy · Z_plastic(section)         [grows as d³]
       available = (rated_torque/rated_current · set_current) · usable_frac · RATIO · eff
     Stepper torque is set by PHASE CURRENT, so the model works back from a target wire to
     the phase current it needs — hence the DRIVER class to spec per machine size. A stepper
     has no overload margin: if you under-set the current you stall (the 0.150" bench stall =
     driver set below the ~1.6A that wire needs). If the required current exceeds the motor's
     rated current, no driver setting helps — it's a bigger-motor / more-ratio problem.

  2. CAPACITY of the printed disc (structural side):
       the output torque reacts through the 6 carrier rollers; the roller→disc-hole
       bearing stress must stay under the print material's allowable, or the holes
       crush/ovalise. Face width (DISC_FACE_W · N_DISCS) is the linear lever here.

The machine can bend a given stock only if it clears BOTH. `max_bendable()` returns
the larger of the two binding diameters so you can see which one to fix.

Section model: solid round wire  Z = d³/6;  tube  Z = (do³−di³)/6  (kind='tube',
wall=…). NOTE for tube the torque model is necessary-but-not-sufficient — tube also
needs a mandrel/wiper against wrinkling + ovalisation, which this does NOT model yet.

    python drive_model.py                              # current machine + driver-current table
    python drive_model.py --current 1.5                # what a 1.5A driver setting can bend
    python drive_model.py --rated-torque 3 --rated-current 4   # spec a NEMA23 for a bigger machine
"""
from __future__ import annotations

import argparse

from machine import (DRIVE_RATIO, DRIVE_EFF, MOTOR_RATED_TORQUE, MOTOR_RATED_CURRENT,
                     MOTOR_SET_CURRENT, MOTOR_USABLE_FRAC, BEND_PROCESS_FACTOR,
                     CARRIER_R, CARRIER_ROLLER_D, DISC_FACE_W, N_DISCS, N_CARRIER)

# Stepper-driver classes by usable continuous phase current (A) — for the "what driver" hint.
DRIVERS = [("A4988", 1.0), ("DRV8825", 1.7), ("TMC2209", 1.7), ("TB6600", 3.5),
           ("DM542 / TMC5160", 4.0), ("DM860 / closed-loop", 6.0)]

# ── design references ────────────────────────────────────────────────────────
# Printable-material BEARING allowable (sustained, derated for creep/heat), MPa.
# Order-of-magnitude from the bend-cell discussion; calibrate against real parts.
MATERIALS = {"pla": 15, "petg": 20, "abs": 22, "nylon": 28, "pc": 38, "pa-cf": 50}

# Common stock: (label, Ø mm, yield σy MPa). σy varies a lot with temper — mild ~400,
# hard-drawn / music wire 1000-1800; these defaults are mid-grade steel.
STOCK = [("16 ga wire", 1.29, 400), ("14 ga wire", 1.63, 400),
         ("0.150\" wire", 3.81, 400), ("1/4\" rod", 6.35, 400)]

# Poor load-sharing in a PRINTED cycloid: assume the worst carrier roller takes this
# fraction of the total tangential force (tolerances let only ~2 rollers engage).
PEAK_CARRIER_SHARE = 0.5


# ── section / torque ─────────────────────────────────────────────────────────
def plastic_modulus(d, kind="wire", wall=None):
    """Plastic section modulus Z (mm³). Solid round d³/6; tube (do³−di³)/6."""
    if kind == "tube":
        di = d - 2 * wall
        return (d ** 3 - di ** 3) / 6.0
    return d ** 3 / 6.0


def bend_torque(d, sigma_y, kind="wire", wall=None, process=BEND_PROCESS_FACTOR):
    """Output torque (N·m) to fully bend the section: process · σy · Z."""
    z = plastic_modulus(d, kind, wall)                    # mm³
    return process * sigma_y * z / 1000.0                 # MPa·mm³ = N·mm -> N·m


def motor_torque(set_current=MOTOR_SET_CURRENT, rated_torque=MOTOR_RATED_TORQUE,
                 rated_current=MOTOR_RATED_CURRENT):
    """Usable motor torque (N·m) at a driver current setting. Torque ~ current up to the
    rated current; beyond rated it saturates (clamped) and just makes heat."""
    return (rated_torque / rated_current) * min(set_current, rated_current) * MOTOR_USABLE_FRAC


def drive_output_torque(set_current=MOTOR_SET_CURRENT, **mk):
    """Deliverable output torque (N·m) = usable motor torque · ratio · efficiency."""
    return motor_torque(set_current, **mk) * DRIVE_RATIO * DRIVE_EFF


def current_for_torque(out_torque, rated_torque=MOTOR_RATED_TORQUE, rated_current=MOTOR_RATED_CURRENT):
    """Phase current (A) needed to deliver `out_torque` at the output — the DRIVER requirement.
    = (motor torque needed) / (torque-per-amp). May exceed the motor's rated current, in which
    case this motor can't do it at any driver setting (need a bigger motor or more ratio)."""
    motor_need = out_torque / (DRIVE_RATIO * DRIVE_EFF * MOTOR_USABLE_FRAC)
    return motor_need / (rated_torque / rated_current)


def current_for_stock(d, sigma_y, kind="wire", wall=None, **mk):
    return current_for_torque(bend_torque(d, sigma_y, kind, wall), **mk)


def driver_for(current):
    """Smallest driver class that can source `current`."""
    for name, cap in DRIVERS:
        if current <= cap:
            return name
    return ">6A (industrial)"


# ── printed-disc capacity ────────────────────────────────────────────────────
def carrier_bearing_stress(out_torque):
    """Worst carrier roller→disc-hole bearing stress (MPa) for a given output torque."""
    total_tangential = out_torque / (CARRIER_R / 1000.0)      # N at the carrier circle
    peak = total_tangential * PEAK_CARRIER_SHARE
    area = CARRIER_ROLLER_D * DISC_FACE_W * N_DISCS           # mm²
    return peak / area                                        # N/mm² = MPa


def disc_torque_limit(material):
    """Output torque (N·m) at which the carrier bearing hits the material allowable."""
    allow = MATERIALS[material]
    area = CARRIER_ROLLER_D * DISC_FACE_W * N_DISCS
    peak = allow * area
    total = peak / PEAK_CARRIER_SHARE
    return total * (CARRIER_R / 1000.0)


# ── capability ───────────────────────────────────────────────────────────────
def _invert_d(t_out, sigma_y, kind, wall, process=BEND_PROCESS_FACTOR):
    """Largest Ø whose bend_torque == t_out (solid only; tube wall fixed)."""
    if kind == "tube":                                   # solve (do³-(do-2w)³) numerically
        lo, hi = 2 * wall + 0.1, 100.0
        for _ in range(60):
            mid = (lo + hi) / 2
            (lo, hi) = (mid, hi) if bend_torque(mid, sigma_y, kind, wall, process) < t_out else (lo, mid)
        return (lo + hi) / 2
    return (6.0 * t_out * 1000.0 / (process * sigma_y)) ** (1 / 3.0)
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

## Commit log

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2026-06-10 Rough in the full machine in the MuJoCo sim + stepper adapter
    - make_mjcf.py now builds the whole machine: feeder body, NEMA17, feed tube,
    drive pulley, U-bracket, tube-rotation motor, and wire as rough primitives,
    with the bending head still using real CAD meshes. All three axes (feed,
    tube_rot, bend) are driven by position actuators. Collisions off (kinematic viz).
    - view.py / render.py updated for the full machine + a "make a shape" demo.
    - stepper-adapter.scad: parametric NEMA17-on-1KGSSJ-B adapter (keeps the existing
    gear reduction via a self-centering register boss). feeder-gear.scad is the
    matching 5mm-bore replacement pinion.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
    [feeder-gear.scad, stepper-adapter.scad]
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2026-06-10 Animate bending on the machine + viewer for predicted shapes
    - animate_bend.py: runs a feed/rotate/bend program ON the machine in the correct
    machine frame (head fixed; formed wire trails out of the head and swings about
    the bending point as each bend forms). Renders a GIF or plays live. Verified the
    formed shapes match bend_model.py exactly (segment lengths + turn angles).
    - make_mjcf.py refactored: ensure_meshes() + parameterized build_model_xml()
    (omit wire/actuators, inject extra geometry) so the animator can rebuild the
    scene per frame. Default model output is unchanged.
    - bend_model.py: --view opens predicted shapes in the interactive viewer; multi-
    shape layout, grid floor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
    [animate_bend.py, bend_model.py, make_mjcf.py]
2026-06-10 Add collision/interference checker + PLAN.md
    interference.py runs a program through the machine and checks the formed wire at
    every frame for self-collision, table, and machine-body contact (exact), plus the
    bending head via the real head mesh (signed-distance). The head check is currently
    approximate — the wire bends around the mandrel into the head cutaway and our
    rough bend kinematics don't model that yet, so it only catches far re-entry; this
    tightens up once bend radius is modeled.
    - self-collision ignores free wire tips so closed shapes don't false-fail on
    their intended closure; spiral_flat is correctly caught self-overlapping.
    - renders the worst frame with the offending wire se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
    [interference.py]
2026-06-10 Model bend radius (arcs) in forward model + animation
    Bends now lay an arc of radius BEND_RADIUS (default 4mm, the wire wrapping the
    mandrel) instead of a sharp corner, tangent to the incoming heading and curving
    toward the bend direction; bend_radius=0 recovers the sharp model. Implemented in
    both the part-frame forward model (bend_model.simulate) and the machine-frame
    animation (animate_bend.frames_for, pivoting the formed wire about the mandrel
    centre C = B + b*r). Verified the two stay congruent (length + diameter match).
    Total wire length now includes arc length (Σ feed + Σ r·α) — the wire consumed in
    each bend. interference.py picks up the arc geometry automatically.
    PLAN.md: b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
    [animate_bend.py, bend_model.py]
2026-06-10 Add slicer: CAD wire path -> machine program -> G-code
    slicer.py is the inverse of bend_model.py. Given the desired wire centerline
    (points file, SVG path, or a built-in example) it walks the path and recovers
    the feed/rotate/bend program, then emits GRBL G-code (X=feed, Y=tube rotation,
    Z=bend).
    - inverse kinematics verified exact (0.000 mm sharp round-trip on all examples)
    - setback compensation: feeds shortened by r*tan(a/2) so the rounded-corner part
    matches the design; residual fit error = the corner-rounding sagitta (~1.4mm
    for 90deg bends at r=4)
    - springback over-bend compensation (1/(1-springback)) in the G-code
    - reports fit error; --check runs the collision checker on the sli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
    [slicer.py]
2026-06-10 Refactor slicer into a pluggable extraction-method framework
    slicer.py now has a METHODS registry: each method turns a source into one or more
    wire paths, feeding the shared backend (slice_path -> program -> fit/collision
    check -> G-code). Methods are auto-detected by file extension or chosen with
    --method; --list-methods enumerates them.
    Registered methods:
    - points (.json/.csv)
    - svg (.svg, 2D paths)
    - example (built-in bend_model shapes)
    - centerline(.stl/.obj/.ply tube mesh -> spine via cross-section marching)
    experimental; round-trips well on chair (0.32mm) and the U staple (102.9 vs
    102.6mm).
    G-code generation is multi-piece aware (separate wire pieces -> cut/reload M0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
    [slicer.py]
2026-06-10 Add cross_section slicing method (FDM-slicer style)
    slicer.py --method cross_section slices a solid mesh on parallel planes
    (--axis, --spacing); each contour loop becomes a wire piece, emitted as a
    separate G-code block with a cut/reload pause. Verified: a sphere -> 6-ring cage
    (fit ~0.3mm, all collision-OK), a box -> stacked rectangles.
    Needs networkx (trimesh path traversal orders the section edges into loops).
    [slicer.py]
2026-06-10 Add edge_follow slicing method (wireframe / pepakura-flavored)
    slicer.py --method edge_follow builds a graph of the model's sharp feature edges
    (--feature-angle) and routes it into wire. Because the bender makes one strand,
    the default decomposes each connected component into the fewest open trails that
    cover every edge once -> separate wire pieces, no overlap (odd-degree vertices
    paired with virtual edges -> Eulerian circuit -> split at virtuals). --single
    instead forces one strand via networkx eulerize, which retraces edges; the wire
    would fold back 180 deg, surfaced as a large fit error.
    Verified: box -> 4 pieces covering all 12 edges, each collision-OK.
    The slicer now has six methods: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
    [slicer.py]
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2026-06-10 Show the real bracket in the sim; fix head-bearing clearance
    make_mjcf.py now renders base-bracket.scad (via OpenSCAD) to a mesh and places it
    as the static frame, replacing the rough base/upright/motor primitives. The
    bracket's spindle axis is aligned to the bending head's wire axis (+90 deg about
    Z + translation); the rotating spindle/pulley were moved to sit between the
    bracket bearings. Falls back to rough primitives if OpenSCAD is unavailable.
    Design finding from the sim: the bending head is a horizontal Ø43 disk the wire
    passes through sideways, so it reaches ±21.5mm ALONG the wire axis. The front
    bearing must clear that -> head set back 35mm (HEAD_SETBACK in base-bracket.scad,
    BRAC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
    [base-bracket.scad, bracket.stl]
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2026-06-10 Finalize feeder motor pocket from measured specs
    - Ø56 pocket clears the feeder's Ø53 motor-mount boss (5mm proud) so the boss +
    motor drop through and the feeder mates flat on the base top.
    - Pocket centre anchored ~32mm inboard of the wide (47.3) mounting holes.
    - Noted the ~48mm motor drop-through clearance (mount bracket on standoffs).
    - Ghost updated to show the boss + motor below.
    Fits the Bambu 256mm bed (233mm long); printing with supports (no teardrop bores
    needed). Spindle axis height kept at 50mm — needed for bending-head rotation
    clearance, which also accommodates the feeder.
    [base-bracket.scad, bracket.stl]
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2026-06-11 Add bend-gears.scad — 3D-printed gear reduction for the bend axis
    In-plane spur reduction so a pancake NEMA17 can bend 14-16 ga 1018 steel while
    keeping the rotating head flat:
    - module 1, 14T pinion -> 56T output gear (4:1, ~0.7 N.m; bump to 70T for 5:1)
    - pinion: 5mm bore + set-screw collar (pancake NEMA17 shaft)
    - output gear IS the bending flange: Ø8 bore for a metal stepped mandrel pin
    (Ø8 journal -> Ø4 mandrel the wire wraps, ~2.8mm bend radius) + M3 shoe screw
    - replaces the inline can-stepper + motor-flange.scad approach
    (Superseded the L-bracket head-adapter first pass; the bending-head housing will
    integrate the spindle interface + gear bearing + motor mount + wire guide.)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
    [bend-gears.scad]
2026-06-11 Add head.scad — integrated bending-head housing (first pass)
    Replaces bender-head/motor/motor-flange with one gearbox-style head built around
    bend-gears.scad: a back wall carrying the 608 mandrel bearing and the pancake
    NEMA17 mount (pinion meshing the output gear up front), a wire guide tangent to
    the Ø4 mandrel (offset ≈2.8mm = mandrel_r + wire_r, the real tight-bend radius),
    and a Ø32/M3 spindle-flange boss. One connected solid, 92x82x32mm. First pass —
    bearing retention, NEMA pocket, wire-guide tangency and proportions to iterate.
    [head.scad]
2026-06-11 Put the new gear-driven bending head in the sim
    make_mjcf now renders head.scad (housing) and bend-gears.scad (output gear) and
    uses them as the bending head: the housing rides on the tube body (Axis 2), the
    output gear is the bend body (Axis 3) rotating about the mandrel. Replaces the
    old motor/bender-head/motor-flange head. Placement maps head.scad's frame
    (Z=bend axis, Y=wire) into the sim via a 180-deg-about-Z rotation + translation
    onto the wire axis. bend-gears.scad gains show="output_gear" to emit just the
    gear. Falls back to the old meshes if OpenSCAD is unavailable.
    [bend-gears.scad, bend_gear.stl, head.stl]
2026-06-11 Add massing.scad — cantilevered rotating-head architecture baseline
    Rough block massing of the agreed architecture: head rotates about the wire axis
    (Axis 2) cantilevered FORWARD of the base, swinging a ~Ø108mm envelope in open
    air. Both motors on the head (bender drivetrain + rotation motor opposite, for
    balance); rotation pinion meshes a fixed gear on the base; feed tube passive in 2
    bearings; feeder flat on the base. Includes a translucent swing-envelope to check
    clearance. Scratch model for proportions, not a part.
    [massing.scad]
2026-06-11 Add base.scad — base for the cantilever architecture (one piece)
    New base for the rotating-head architecture, replacing base-bracket.scad's
    belt-drive approach:
    - fixed external gear (40T, m1.5) coaxial with the wire axis; the head's rotation
    pinion meshes its outside to drive Axis 2 (~4.3:1), no belt/tensioner/motor on
    the base
    - 2 passive 608 bearings for the feed tube (front one tight behind the gear to
    keep the head cantilever short); gear held by a backing annulus AROUND the
    bearing (coaxial with the tube)
    - 1KGSSJ-B feeder mount (Ø56 motor pocket + trapezoidal Ø5.3 bolts, flat on top)
    - one connected solid, 214mm (fits the Bambu bed); front edge behind the gear so
    the can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
    [base.scad]
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2026-06-11 Add feeder narrow-end boss pocket to the base
    The feeder seats on two proud bosses: the Ø53 motor boss (wide end) and a ~Ø20
    boss on the narrow nose. Added a Ø22 clearance pocket for the nose boss, just
    forward of the narrow bolt holes (estimated from the photo; ~5mm proud so a
    through-hole in the 6mm base clears it). Still one connected piece.
    [base.scad]
2026-06-11 Add rothead.scad — rotating head massing (cantilever architecture)
    Block massing of the head: tube-clamp hub at the wire axis; bender drivetrain
    (gutted servo + tiny stepper -> layshaft -> Ø4 mandrel + shoe) on +Z; rotation
    motor opposite on -Z with its 12T pinion meshing the base's fixed gear (ghost).
    Confirms the balanced two-motor layout and the ~Ø110 swing. Bender side is
    heavier -> bring it inboard to balance the rotation motor (fixed at the 39mm mesh
    radius), which also shrinks the swing. Drivetrain internals are next.
    [rothead.scad]
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2026-06-12 Port the base to build123d (cad/base.py + cad/gears.py)
    Move CAD to build123d (OpenCASCADE) for real B-rep solids: proper boolean unions
    (no disconnected bodies), true fillets, and a real involute spur-gear generator
    (cad/gears.py) replacing the MCAD dependency. cad/base.py reproduces base.scad as
    one watertight fused solid (214x80x69mm) with filleted gusset junctions and the
    40T fixed gear; exports build/base.{stl,step}. base.scad is now superseded.
    [base.step, base.stl]
2026-06-12 Port the rotating head to build123d (first structural pass)
    cad/rothead.py builds the head as one watertight solid (replacing the broken
    OpenSCAD massing): tube-clamp hub with pinch slit + M3 lug, balanced arms to the
    bender pad (+Z, inboard) and rotation pad (-Z, at the 39mm mesh radius), and a
    mandrel boss + wire-guide rib near the wire axis. Motors/pinion/mandrel are
    ghosts (bought parts). Exports build/rothead.{stl,step} + an assembly STL.
    Still open: the bender drivetrain orientation (servo output -> Y-axis mandrel
    gear train) and the real motor mounts/bolt patterns.
    [rothead.step, rothead.stl, rothead_assembly.stl]
2026-06-12 Add MuJoCo model for the build123d cantilever architecture
    sim/make_mjcf_v2.py assembles build/base.stl (static) + build/rothead.stl
    (rotates about the wire axis = Axis 2) + the passive feed tube into
    wirebender_v2.xml. sim/view_v2.py launches the interactive viewer. This replaces
    the old-architecture sim for the new build123d parts; Axis-2 head rotation works.
    [base_v2.stl, head_v2.stl]
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2026-06-12 Delete legacy OpenSCAD architecture; make the build123d sim the only sim
    Removed the superseded OpenSCAD parts (base.scad, base-bracket.scad, head.scad,
    bend-gears.scad, bender-head.scad, motor.scad, motor-flange.scad, massing.scad,
    rothead.scad, spindle.scad) and the old MuJoCo sim that rendered them
    (sim/make_mjcf.py old, view.py old, animate_bend.py, interference.py).
    Promoted the build123d sim to be THE sim: make_mjcf_v2.py -> make_mjcf.py,
    view_v2.py -> view.py, wirebender_v2.xml -> wirebender.xml (clean names, meshes
    base.stl/head.stl). slicer.py's optional --check now degrades gracefully without
    interference.py. Kept the feeder-conversion .scad and the forward-model/slicer
    toolchain.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
    [base-bracket.scad, base.scad, bend-gears.scad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]
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2026-06-13 Cycloidal bend-head architecture + full 2-axis sim
    - cad/parts.py: real NEMA17 (pancake) model (chamfered body, pilot, shaft, M3s)
    - cad/bend_endcap.py: custom cycloidal output — pulls the Sweep Dynamics End_Cap
    out of the purchased STEP and adds the sweeping bend pin (PIN_R = bend tightness/
    spacing knob). Vendor geometry not committed; regenerate locally.
    - cad/rothead.py: head massing reworked for the cycloidal bend axis (+Z bend
    actuator = cycloidal + pancake; -Z rotation pancake doubling as counterweight,
    its 12T pinion on the fixed gear)
    - sim/make_mjcf.py: full machine — head assembly (Axis 2) + the bend die (Axis 3)
    on the bend axis. wirebender.xml now drives both axes.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
    [make_mjcf.py]
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2026-06-13 Fix feeder mount + drop the wire axis to match the feeder
    From real measurements of the 1KGSSJ-B feeder:
    - wire axis lowered to 29mm above the base top (= 35mm above the deck, given the
    6mm plate); bearing uprights shorten accordingly. The Ø63 fixed gear now dips
    below the base and hangs off the front overhang (machine is cantilevered).
    - nose boss moved to 16mm BEHIND the front bolt-hole line (inboard, on the body)
    -- was wrongly 6mm beyond it, off the perimeter
    - feeder shifted back so its nose clears the rear bearing upright by ~14mm (its
    output tube reaches ~35mm further forward into the spindle)
    [make_mjcf.py]
2026-06-13 Put the real feeder body in the sim (clearance reference)
    cad/gen_feeder.py bakes the image-derived feeder GLB (extruder.glb) to a sim mesh
    (scaled to the 122mm body length; nose=-X, mounting face=-Z, knob up). make_mjcf
    places it on the base — mounting face on the deck, nose facing the head — so the
    14mm clearance and the 35mm wire-output height are visible end to end. Makefile
    gains the build/feeder_body.stl target.
    [make_mjcf.py]
2026-06-13 Bring back the wire-feeding-and-bending animation + feeder fixes
    sim/animate_bend.py: rebuilt for the X-axis machine. Reuses bend_model's forward
    model; each frame re-injects the formed wire (capsules) into wirebender.xml and
    drives tube_rot (Axis 2) + bend (Axis 3). Wire deflects in -Y so the bend axis =
    the cycloidal Z (horizontal bends), viewed from the front so the head doesn't hide
    it. Renders a GIF per program (make anim NAME=staple|square|chair|coil).
    make_mjcf.py: feeder body was backwards -> flipped 180° (output faces the head);
    raised it so the output sits on the wire axis.
    [animate_bend.py, make_mjcf.py]
2026-06-13 Lower wire axis to seat feeder, add layout-test slice + G-code runner
    - base: AXIS_Z 29->15mm so the feeder sits flat on the base and its output
    lines up with the feed tube; uprights drop ~14mm, fixed gear hangs off the
    front (cantilever). Nose boss pocket 22->24mm.
    - make_mjcf: world wire axis 35->21mm; feeder mounting face now lands on the
    base top.
    - base_thin.py: thin slice of the plate (footprint + all holes) for a layout
    test print.
    - slicer: parse_gcode() — inverse of to_gcode (verified 0.0-diff round-trip).
    - animate_bend: accept a .gcode file or any sliceable model, not just the
    built-in examples (run a sliced part in the sim).
    - Makefile: `make slice` and `make run` tar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
    [animate_bend.py, make_mjcf.py, slicer.py]
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2026-06-14 Head: real cycloid base, 2-piece slotted bracket checkpoint + PLAN
    - rothead: bend mount is the cycloid's own integrated NEMA base
    (nema-17-cycloid-base.stl, vendor/gitignored, bearing-boss-down toward the
    wire) instead of a printed plate; placeholder-block fallback if absent.
    - Split the head into 2 flat-printable pieces with adjustment slots: piece 1 =
    tube clamp + rotation arm + slotted NEMA mount (gear-mesh, +/-2) + join pad;
    piece 2 = slotted tabs (height, +/-5) gripping the cycloid base +X face.
    - sim: drop the redundant separate cyclo geom (now part of head.stl); Makefile
    PARTS no longer needs the vendor STEP bake.
    - PLAN.md: write up the simpler 2-part head redesign (main b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
    [make_mjcf.py]
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2026-06-15 Add manufacturability rule-checker (interference.py)
    Flag-only checker for the single-pin bend cell: walks a program (bend_model
    kinematics) and reports per-bend violations of the machine limits.
    Rules: travel (bend cmd > 270° die range), min_straight (inter-bend straight <
    setback + pin grab; the fixed mandrel radius surfaces here), pin_part (pin sweep
    strikes the formed part), pin_tube (wrap > MAX_WRAP swings the pin toward the
    tube), part_head (part swings back into the head). Bend radius is fixed by the
    mandrel (BEND_RADIUS = mandrel_r + wire_r).
    - interference.py: capabilities()/check()/summary() + CLI (example|.gcode|--caps).
    - slicer.py --check: now prints the rule report (old mesh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
    [interference.py, slicer.py]
2026-06-15 Single source of truth (machine.py) + enforce bend limits in the sim
    Make the CAD, MuJoCo sim, forward model, slicer, and rule-checker describe ONE
    machine, and fault the sim when a program violates the limits.
    - machine.py (new): canonical machine params — axis heights, feed tube, mandrel/
    pin/die, wire, derived BEND_RADIUS, and the calibratable rule limits.
    - bend_model / interference / check_pin / make_mjcf / animate_bend now read their
    constants from machine.py (removes the duplicated/contradictory copies).
    - consistency.py (new) + `make check-consistency`: assert machine.py matches the
    CAD constants (cad/base, rothead, bend_endcap) so it can't drift from the parts.
    - animate_be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
    [animate_bend.py, bend_model.py, check_pin.py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]
2026-06-15 Fix bend-die orientation so the default sim sweep clears the tube
    The benddie geom carried a 180°-about-X flip that pointed the die/pin DOWN
    through the on-axis feed tube — buried -10.4mm at every angle. Removing the flip
    (body points +Z, away from the wire) clears the tube by +4mm across the FULL
    envelope: head roll ±92° and bend ±270°, including simultaneous motion (verified
    with mj_geomDistance, the query MuJoCo's own collision uses).
    - make_mjcf.py: drop the benddie quat (identity); move the pin site to match.
    - view.py: default animation now sweeps each axis through its limit back and
    forth — head roll across its joint range, bend die across ±half the 270° die
    travel (ma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
    [check_pin.py, make_mjcf.py, view.py]
2026-06-15 Assemble the sim from printable STLs; animate the gear mesh
    The sim no longer uses a fused rothead_assembly.stl that baked purchased motors +
    cyclo + pinion into one printable-looking mesh. Now:
    - Sim assembles the PRINTABLE part STLs individually (base, rothead rot+bend,
    pinion, bend die) — what you see is what you print.
    - Purchased parts (NEMA motors + cycloid drive) are shown as a clearly-separated
    REFERENCE mesh, build/head_refs.stl (new cad/head_refs.py; placements imported
    from rothead.ghosts(), the design authority). Never fused into a printable STL.
    - rothead.py stays clean: emits the printable head pieces only (rot/bend/rothead.stl),
    no assembly-with-ghosts export. ghost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
    [animate_bend.py, consistency.py, machine.py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]
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2026-06-15 Remove the dead old-assembler subsystem; refresh the docs
    assemble.py + manifest.yaml were the old CadQuery manifest-driven assembler,
    superseded by the build123d cad/ pipeline + cad/assembly.py + sim/make_mjcf.py
    (and broken — the manifest pointed at .scad files that no longer exist).
    - Delete assemble.py, manifest.yaml, motor.glb (only the old assembler used it),
    and the orphaned stale STLs bender-head.stl, motor-flange.stl.
    - README.md: drop the assemble.py/manifest sections; document the current
    Makefile + build123d + sim pipeline and the real bending-head design.
    - sim/README.md: rewrite to match reality (printable-STL assembly, the actual
    joints incl. pinion_spin, the rebuilt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
    [bender-head.stl, motor-flange.stl]
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2026-06-16 Hub for the real 1/4" feed tube: smaller bore + smaller OD
    The feed tube is 1/4" (6.35mm), not 8mm. TUBE_D 8.0 -> 6.35 (rothead + machine,
    consistency-checked). The flat head's tube-clamp hub shrinks Ø16 -> Ø13. The
    3.1mm wall is too thin to bury a 5mm M3 insert (it would poke into the bore and
    block the tube), so a small +Y set-screw boss gives the insert full depth — the
    insert seats clear of the bore and the grub clamps the tube. Single watertight
    solid; bore verified clear.
    [machine.py]
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2026-06-16 Wire the new bend parts into the sim (approx placement)
    Replace the old cyclo ghost with the new bend parts: arbor_mount (cyclo housing
    + standoff posts, output/posts toward the wire) and bend_plate (cyclo base +
    boss) above it, with the bend pancake on top (shaft shortened so it no longer
    pokes through). ghosts() drops cyclo_base (shown via arbor_mount.stl now) and the
    bend motor sits at the top of the stack. Placement is APPROXIMATE — the reach
    from the head's bending plate to this stack is the arbor still being designed.
    [make_mjcf.py]
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2026-06-16 Rework the bend cell: parametric end_cap/housing, bend_disc, taller posts
    - end_cap.py: rebuild the cyclo End_Cap as a clean parametric revolve + 6 M3
    counterbores (Ø42 flange turned down to Ø40). The vendor solid has degenerate
    faces that break 4 of 6 holes into non-watertight shells, so it sliced with only
    2 holes; the rebuild is watertight. Replaces the deprecated bend_endcap.
    - housing.py: extract vendor Housing_v1 (the 20-pin cyclo ring) from the assembly
    STEP into its own first-class part; arbor_mount imports it (single source).
    - arbor_mount.py: mount posts now 4mm proud (was 2mm) for extra clearance.
    - bend_disc.py: Ø60x2 disc bolting to the arbor posts (4x M3 csk + centre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
    [make_mjcf.py]
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
